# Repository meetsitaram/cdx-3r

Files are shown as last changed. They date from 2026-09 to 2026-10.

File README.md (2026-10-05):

# CDX-3R

A right-arm exoskeleton made of 3D-printed parts, PVC pipe and off-the-shelf bearings, designed around a
3D scan of the wearer's body. **3R** = three revolute joints on the right arm: shoulder abduction, shoulder
flexion and elbow flexion.

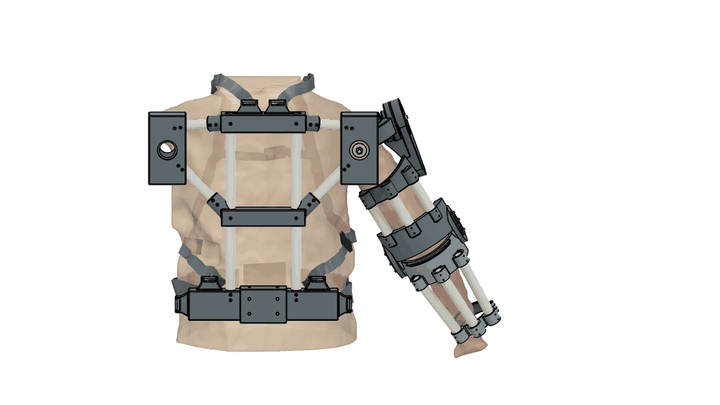
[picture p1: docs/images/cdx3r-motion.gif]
CDX-3R: shoulder and elbow motion


*Elbow to 100 degrees, shoulder forward to 70 and out to 45, back to rest; the scanned arm moves with the exo. Rendered from the Fusion models. [Video](docs/images/cdx3r-motion.mp4)*

> Work in progress. The passive structure (frame, joints, harness) is designed and being test-printed;
> actuation (motors, cables, battery) is not designed yet. Not a certified device.

## How it works

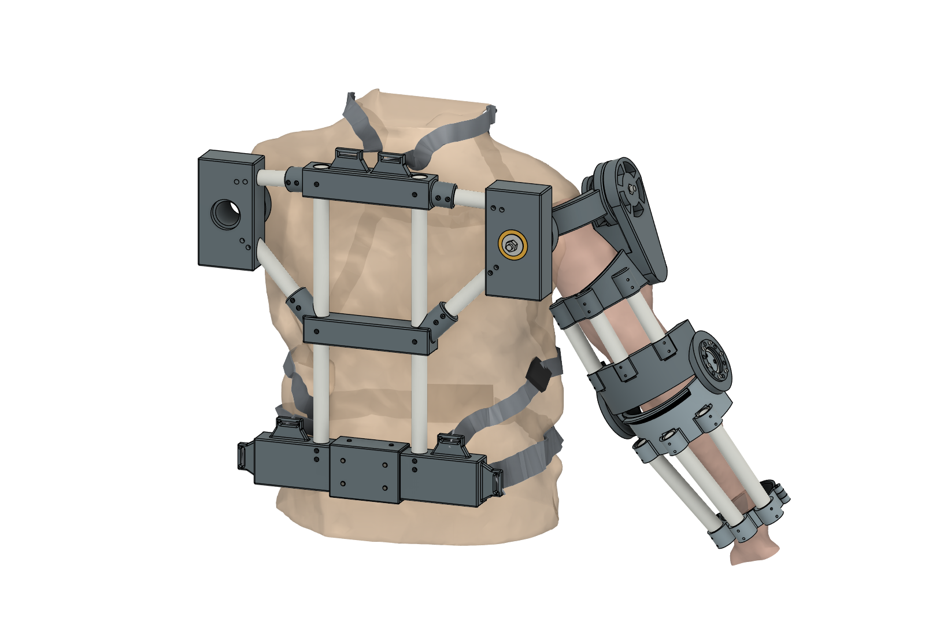
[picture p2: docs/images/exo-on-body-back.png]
Back view: frame, shoulder hinges, arm


**Back frame.** Two vertical PVC pipes (21.5 mm OD) form the backbone. They're held by printed top, mid and
bottom joints and braced to a mount block behind each shoulder by an upper beam and a diagonal, a triangulated
frame that carries the arm's loads into the back and the waist belt. The frame is symmetric (the left side is a
Fusion mirror of the right) so the weight sits centred. The left mount block is free for a battery or a future left arm.

**Harness.** Worn like a backpack: two shoulder straps, a sternum strap and a waist strap, all 1" webbing
with side-release buckles, through six printed strap tabs on the frame.

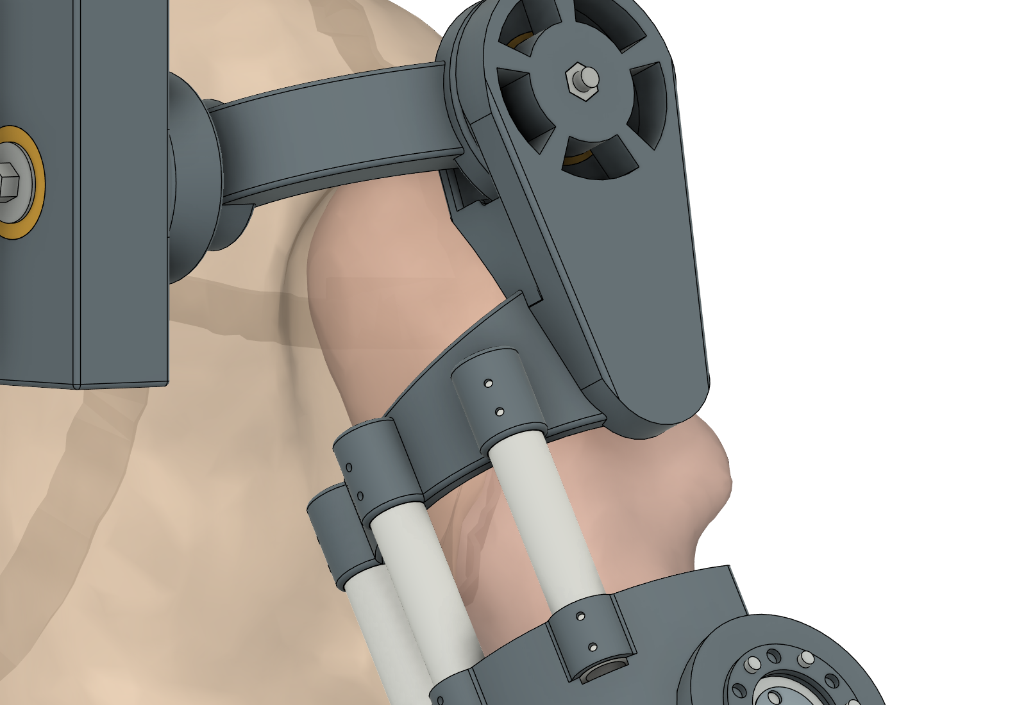
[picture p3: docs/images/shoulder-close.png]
Shoulder: abduction and flexion hinges, upper-arm link


**Shoulder (2 joints).**
- *Abduction* (arm out to the side): a hinge behind the shoulder on 2 × 6806 bearings in the mount block,
  clamped by an M8 through-bolt. A curved yoke carries it round the back of the shoulder.
- *Flexion* (arm forward/back): a hinge on the outside of the shoulder on 2 × 6808 bearings in the yoke's
  Ø88 housing (the same size as the elbow hub).
- Both hinge axes pass through the shoulder joint's centre, so the exo moves with the arm instead of sliding on it.
- *Upper-arm link:* one printed piece: a fork round the flexion hinge (spoked, so the bearing shows), a
  Y-gusset and a pipe head that holds the three upper-arm pipes in blind sockets. It also acts as the
  backward stop at about -25 degrees.

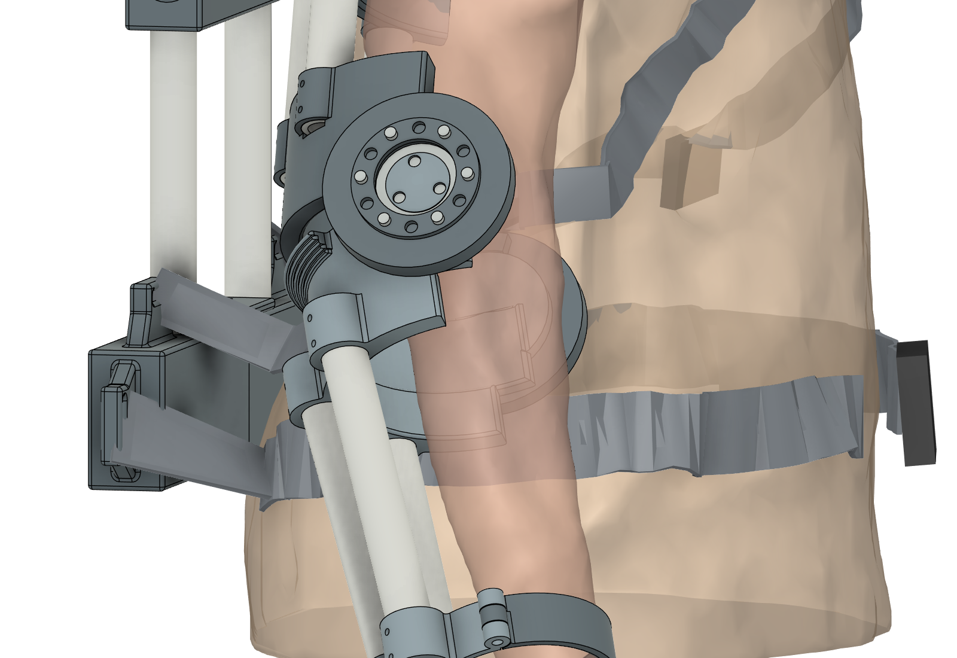
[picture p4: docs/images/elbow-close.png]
Elbow: two-sided bearing joint


**Elbow.** Upper-arm and forearm units are three rear PVC pipes each, joined at a two-sided hinge on
2 × 6806 bearings with bolted axles and spoked covers. Built-in stops at straight and 135 degrees flexion. Nothing
hard sits on the front of the arm near the elbow, so there's no biceps pinch. A hinged wrist ring with a cuff holds
the forearm.

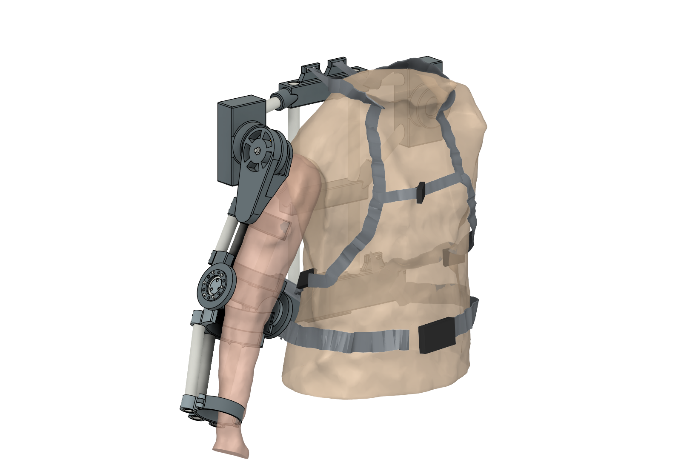
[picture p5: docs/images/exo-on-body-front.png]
CDX-3R on the scanned body


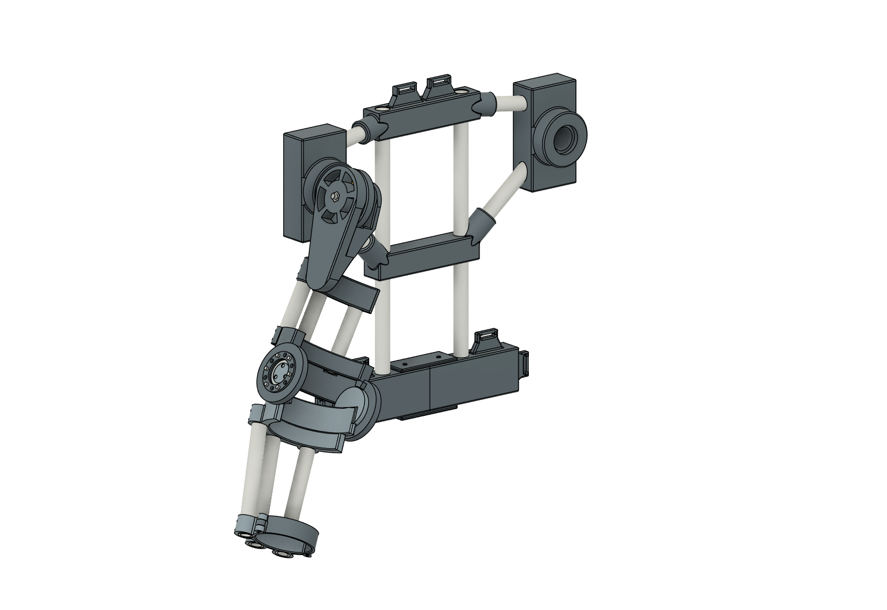
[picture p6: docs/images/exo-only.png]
Exo only


## Fitted to a body scan

The wearer was captured as a Gaussian splat. `cad/scan/` turns it into a clean body mesh with landmarks
(shoulder joint centre, elbow, wrist). The layout and every part are checked against it: collisions,
clearance to the body at rest (the arm rests at 20 degrees abduction) and over the shoulder's range
(abduction 20–60 degrees, flexion -20 to 120 degrees), plus the elbow's 0–135 degree sweep.

## Build it

| What | Where |
|---|---|
| Step-by-step assembly guide, with animations and PVC cut lengths | [docs/ASSEMBLY.md](docs/ASSEMBLY.md) |
| Parts to buy (bearings, screws, inserts, webbing), with links | [BOM.md](BOM.md) |
| Print files (Bambu P1S, PETG), orientation, assembly | [prints/shoulder-back-v2/](prints/shoulder-back-v2/) and [prints/elbow-test-v10/](prints/elbow-test-v10/) |
| Fusion models | [cad/fusion/models/](cad/fusion/models/) (`cdx-3r-shoulder-back.f3d`, `cdx-3r-elbow-concepts.f3d`) |
| Scripts that build the models | [cad/fusion/](cad/fusion/) (`shoulder.py`, `concepts.py`, `fxlib.py`) |
| Body-scan pipeline | [cad/scan/](cad/scan/) |
| Lessons learned (read before changing the design) | [cad/fusion/LESSONS.md](cad/fusion/LESSONS.md) |

## Not done yet

- Actuation: motors, cable drive, battery, controller.
- Wrist-cuff latch (a magnet-assisted snap latch is planned).
- Dedicated shoulder stop pads (abduction 60 degrees, flexion 120 degrees).
- Shoulder-girdle motion (shoulder blade forward/back and shrug): parked, see [docs/extensions/shoulder-girdle-dof.md](docs/extensions/shoulder-girdle-dof.md).

## Website

The design portal site lives in `src/`:

```bash
npm install
npm run dev     # http://localhost:8080
```

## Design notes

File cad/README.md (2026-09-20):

# CDX-3R CAD — piece by piece

Not a 7-axis arm. Three revolute joints, right side.

| Order | Stage | Status |
|---|---|---|
| 1 | **Elbow** — hinge, antagonist sheave, cuffs | `elbow/` |
| 2 | **Shoulder** — flexion (lateral) + abduction (posterior) | `shoulder/` |
| 3 | **Backpack** — 3 winches, battery envelope, ODrive S1 | `backpack/` |
| 4 | **Connect** — one system, saddle + hip belt take the weight | `system/` |
| 4 | Connect — Bowden runs, cable comb, hard stops as a system | after pack |
| 5 | **Armor** — circular window around the sheave | `armor/` |

**Rule:** metal takes the load. Print the fixtures that hold the metal.

Open `elbow/` first. Do not print the whole suit.

## Current revision

[Revision C — articulated assembly](system/README.md#revision-c--articulated-inspection-model)
adds three joint controls, moving shells and hardware, and approximate flexible
cable routing to the system viewer.

[Revision B — rebuilt shells](armor/README.md) adds segmented shoulder armor,
tapered arm panels and a passive wrist collar, with a synchronized full assembly.

```bash
python -m pip install -r cad/requirements.txt
python -B cad/build.py
python -B -m unittest discover -s cad/tests -v
python -B cad/render_previews.py
```

The scripts work from this checkout without `/workspace` paths. STL units are mm.
Both local and public exports are produced from the same normalized meshes.
`cad/render_mesh.py` renders the actual STL surfaces locally with a depth buffer.

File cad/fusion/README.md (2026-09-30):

# CDX-3R in Autodesk Fusion

Fusion models built from this repo's CAD, and the scripts that build them. Scripts run inside
Fusion (Fusion MCP or Utilities > Scripts and Add-Ins); units are mm.

## Models (`models/`)

| File | What |
|---|---|
| `cdx-3r-elbow-concepts.f3d` | Current elbow design (concept B): PVC-pipe arm units (3 rear pipes, 2 self-tapping screws per pipe joint, forearm tapering to the wrist), two-sided 6806 bearing joint with bolted axles (pilot + 3 × M3), M3 covers, elbow shells, hyperextension ledge and 135° flexion stop, side-opening wrist cuff, rounded skin-side edges, fit coupons, and all bought hardware modelled. Repeated features are patterns / mirrors of one seed. Built by `concepts.py`. |
| `cdx-3r-shoulder-back.f3d` | Shoulder + back system on the exoarm2 body scan: PVC back frame (mirrored L/R), strap anchors, split bottom node with U-channel splice, abduction mount blocks (2 x 6806, M8 through-bolt), yoke, one-piece upper-arm link (6808 fork hinge, spoked hub, pipe head + brace wall), all hardware, the elbow (copied, posed at the scanned 12 deg), scan reference and harness illustration. Built by `shoulder.py`. |
| `cdx-3r-full-arm.f3d` | The whole existing CDX-3R (elbow, shoulder, backpack, system, armor, wearer) rebuilt as Fusion solids from `cad/*/build_stl.py`, plus the imported reference STLs. Built by `build.py`. |

Open with Fusion: File > Open > Open from my computer.

## Scripts

- `concepts.py` - the elbow concept. Edit `P` at the top (arm sizes, pipes, bearing, axle, screws,
  cuff, stops) and run `concepts.main()`; it rebuilds and re-runs the collision sweeps (elbow
  0-135°, cuff 0-100° at elbow 0° and 90°). The stop, pipe-path, hardware-fit and soft-tissue
  checks used during design are in the session notes of the test-print READMEs.
  `export_stls()` writes the test-print set.
- `build.py` + `fxlib.py`, `elbow.py`, `mech.py`, `armor.py` - the full-arm rebuild, one stage per
  subsystem; `check` compares every part with its reference mesh (all 114 layers within 0.85 mm).

Runner (Fusion MCP / script):

```python
import sys, importlib
sys.path.insert(0, r'<repo>\cad\fusion')
import fxlib, concepts
for m in (fxlib, concepts): importlib.reload(m)
def run(context): concepts.main(('B',))
```

Test prints: `prints/elbow-test-v10/` and `prints/shoulder-back-v2/` are current (see its README). Earlier folders are kept for
reference; each README says what changed.

Shoulder + back (`shoulder.py`): run `main()` (frame), then `main2()` (moving side), `place_elbow()`, `add_harness()`
and `show_reference_smooth()`; `export_print(dir)` writes the print set. Rebuilding the frame removes the arm side, so
always run `main2()` after `main()`. Keep each call short (the MCP call times out on very long runs). Lessons learned
building both are in `LESSONS.md`; the body-scan pipeline is in `cad/scan/`; bought parts are in `BOM.md` at the repo root.

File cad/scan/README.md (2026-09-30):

# Body scan → exo layout (exoarm2)

These scripts turn the exoarm2 Gaussian-splat body scan into a clean body mesh, lay out the exo on it and check clearances.
The working copy (with the large scan meshes) lives in `C:\Users\PC\projects\exoarm2-scan`. `cad/fusion/shoulder.py`
reads `exoarm2-scan/out/...` from there. This folder is the versioned copy of the scripts plus `layout/layout.json` (the
landmarks and frame points the Fusion model is built from).

The frame is mm, X forward, Y up, Z right; floor at Y = 0. Tools need Python 3.12 with numpy, scipy, open3d, trimesh, manifold3d,
shapely, scikit-image and matplotlib.

| Script | What |
|---|---|
| `splat.cs` | C# SPZ decoder/renderer (no Python needed) |
| `body.py` | splat → body point cloud, levelled and yaw-aligned (`body_pts.ply`) |
| `solid.py` / `mesh.py` | watertight body solid (voxel close + fill + marching cubes) |
| `landmarks.py` / `sections.py` | slice measurements and section plots (shoulder GH, elbow, wrist) |
| `layout.py` | layout + distance fields; rest pose (20° abduction); writes `layout.json` |
| `trim.py` | Fusion reference meshes (torso hips → neck without head/left arm; right arm to wrist) |
| `harness.py` | webbing + buckles illustration routed over the torso |
| `check_fusion.py` | clearance of the Fusion-exported parts to the body + shoulder ROM sweep |
| `com.py` | mass and centre of mass |
| `rest.py`, `study_ua.py`, `render.py`, `viewer.py`, `fmcp.py` | shoulder-rest study (dropped), upper-arm study, renders, three.js viewer, a direct Fusion MCP client (fallback only) |

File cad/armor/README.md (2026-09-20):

# Revision B — shoulder-to-forearm shells

The operator-view reference drives the panel coverage: a segmented shoulder cap, long tapered upper-arm and forearm panels, contrasting borders, narrow light strips, an open elbow joint, and a passive wrist collar.

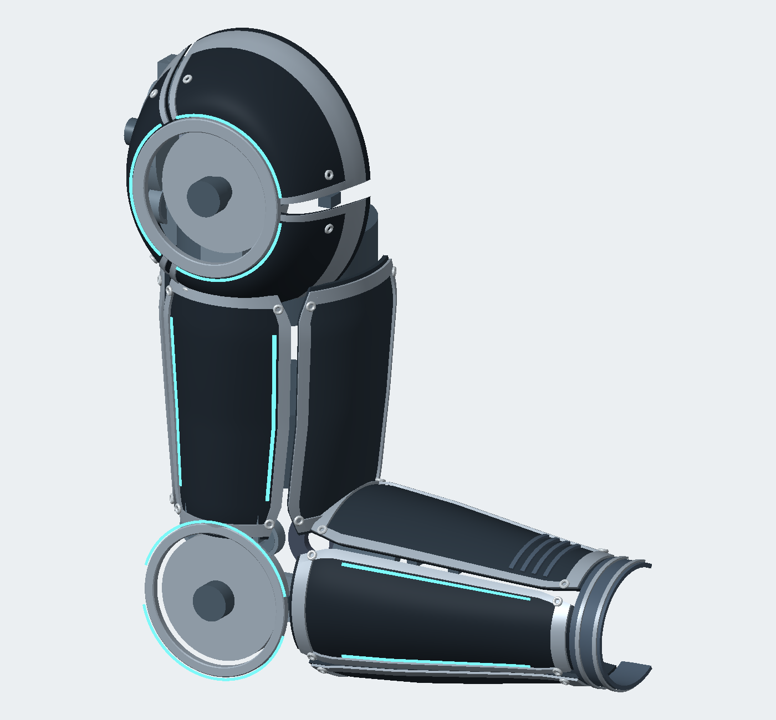
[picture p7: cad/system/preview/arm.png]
Actual revised CAD, with the mechanical joints


The image is rendered directly from the exported STLs. It is not an AI-generated replacement for the CAD.

## Geometry and files

- Three separately closed shoulder panels surround the actual flexion axle. There is no duplicate cosmetic sheave stack.
- The main upper-arm panel spans 178 mm along the limb, increased from 108 mm. The forearm panel spans 201 mm, increased from 106 mm.
- Front and rear wings wrap around each limb with gaps between panels. Borders and light strips follow the same parametric surfaces.
- The main limb walls are 3.2 mm; the shoulder panels are 3.5 mm. The wrist collar is passive.
- Each primary panel has its own `print_fairing_*.stl`. `print_fairing_ua` and `print_fairing_fa` are center panels; `_front` and `_rear` are separate wings. `print_fairing_pack_tub` is now the left pack rail, with a separate right rail, crown, bridges and battery lid.
- Hardware heads, trim and lights are separate assembly layers. The visible fasteners are reference details; mounting holes, inserts, brackets and motion clearance still need a fabrication-detail pass.

Source: [build_stl.py](build_stl.py). Common dimensions: [params.json](../params.json) and [design.py](../design.py). Surface construction: [surfaces.py](../surfaces.py).

## Rebuild and inspect

From the repository root:

```bash
python -B cad/build.py
python -B -m unittest discover -s cad/tests -v
python -B cad/render_previews.py
```

Install the packages in `cad/requirements.txt` if needed. The outputs in `cad/*/stl` and `public/cad/*` are generated together, with matching manifests. The web viewer uses these manifests and retains a complete combined assembly if any colored layer fails to load.

The original five geometry checks cover export synchronization and completeness, closed single-solid shell topology, pack envelope separation, joint/window alignment, and sleeve coverage/cuff clearance. They do not establish collision clearance through the full motion range or structural load capacity.

## Layout changes supporting the shells

Both flexion axes are parallel to world Z; the elbow is directly below the shoulder. The previous whole-elbow 45° yaw is removed. The abduction sheave and its mounting ring now use world X as their rotation axis.

The pack has three transverse winch bays at 90 mm spacing, controllers behind the motors, and a separate lower battery compartment. The existing compact battery envelope has been rotated to 220 × 76 × 52 mm. A specific battery part remains to be selected; the old Hailong purchase reference did not match that envelope.

## Articulated integration

[Revision C](../system/README.md#revision-c--articulated-inspection-model) assigns each
panel and its trim, lighting and fasteners to the appropriate joint. The shell
contours and printable parts are unchanged; grouping layers are now split by
rigid attachment. Use the system viewer to inspect movement with the mechanisms.

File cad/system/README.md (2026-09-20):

# CDX-3R system

Elbow + shoulder + backpack as **one structure**.

The exo does **not** hang on the arm.

```
  [pack] --yoke--> [SADDLE on trapezius]
                       |
                    UA beam (lateral)
                       |
                    elbow
                       |
                  PARK REST  (forearm sits here)
                       |
                    HIP BELT
```

- **Amber saddle** — rests on the shoulder. This is the rest position for the exo.
- **Yoke** — saddle load goes into the pack, then the hip belt.
- **Cuffs** — couple assist torque to the limb. They are not a hanger.
- **Red park rest** — forearm shelf in rest. You can take your arm out. The exo stays.

If the biceps are holding the suit, the load path is wrong.

## Revision B

The full assembly now includes every current shell and mechanism layer. The
shoulder and elbow use shared datums from `cad/design.py`; all exported views
use the same work pose. The elbow flexes forward without the former 45° yaw.
The pack has separated winch bays, rear controllers and a lower battery envelope.
The system harness replaces disconnected subsystem cable extensions.

See [shell revision and verification](../armor/README.md).

## Revision C — articulated inspection model

The portal's **Motion → Articulated assembly → Load 3D** view now moves the
actual CAD layers. It provides shoulder abduction, shoulder flexion and elbow
flexion sliders, four pose presets, a motion sequence, shell visibility, joint
axis arrows and a fit-view button. The same controls appear in the full system
viewer. Individual elbow/shoulder kit viewers remain static part inspections.

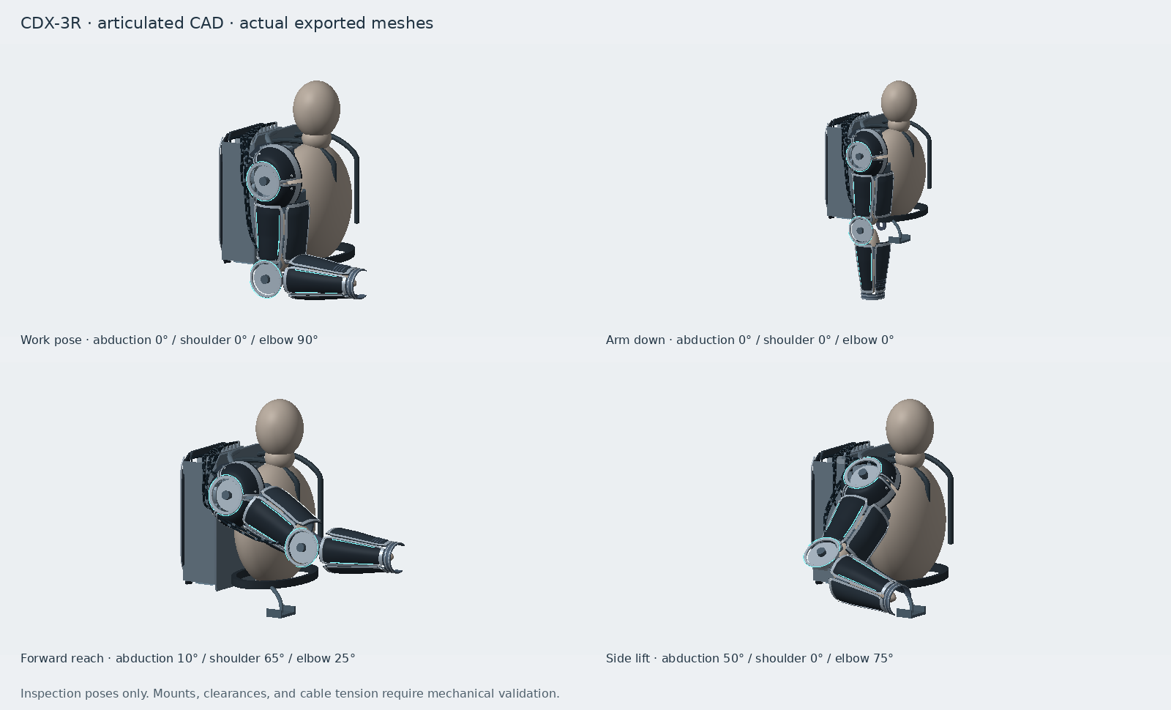
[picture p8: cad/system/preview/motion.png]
Actual CAD in four joint poses


The 114 assembly layers contain the same 106,020 triangles as the previous
79-layer assembly. The additional layers separate upper-arm and forearm trim,
fasteners and lights, the two shoulder joints' fittings, the mannequin limbs,
and individual harness routes. Shell contours and print parts are unchanged.

### Joint convention

The source STLs stay in the work pose: upper arm down, forearm forward. The
exported `asm/colors.json` contains a `motion` block with joint hierarchy,
rest-world axle origins, axes, layer ownership and flexible routing weights.
`cad/motion.py` is the source of that contract. The Three.js viewer builds nested
joint groups from it; it does not infer a hinge from each mesh's bounding box.

| Joint | Parent | Positive direction | Inspection range | STL rest angle |
|---|---|---|---|---|
| Shoulder abduction | Torso/pack | Outboard, about −X | 0–60° | 0° |
| Shoulder flexion | Abduction yoke | Forward, about local +Z | 0–90° | 0° |
| Elbow flexion | Upper arm | Bend from extension, about local +Z | 0–135° | 90° |

The shoulder cap belongs to the abduction yoke. Upper-arm panels and their trim
follow shoulder flexion; forearm panels, cuff, distal plate and passive wrist
follow elbow flexion. The pack, straps, saddle and parking cradle stay fixed.
The body ghost is split so its two limb segments follow the same joints.

Flexible housings and collars blend between their fixed pack attachment and
moving joint attachment. Exposed cable shapes also deform for inspection.
This approximation does **not** preserve cable length, model tendon tension,
solve sheave contact, or verify bend radius. The ranges above are provisional
inspection ranges; they are not certified hard-stop limits or collision-free
motion envelopes. Visible fasteners still need mating mounts and holes.

### Verify and reproduce

```bash
python -B cad/build.py
python -B -m unittest discover -s cad/tests -v
pnpm run test:cad-motion
pnpm run typecheck
pnpm run build:dev
python -B cad/render_motion.py             # four-pose evidence sheet
python -B cad/render_motion.py --animate   # also generate a fixed-camera GIF
```

The nine Python checks cover the earlier geometry/export checks plus ownership,
rest-pose identity, joint closure and segment lengths, and routing endpoints.
Seven TypeScript checks exercise the actual Three.js hierarchy, combined angle
sweeps, shell visibility, malformed metadata, bounded inputs, and cable endpoints
without incremental-transform drift. These checks do not test physical loads
or prove surface collision clearance. There is no hardware-control connection.

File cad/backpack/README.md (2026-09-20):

# CDX-3R backpack

Revision B: three transverse winches in separate bays, controllers on the backplane, and a lower compact-battery compartment. The frame is 250 × 392 × 120 mm.

The modeled battery is an **unselected 220 × 76 × 52 mm envelope**. It is the previous compact block rotated into the lower bay, not a Hailong battery. The final battery selection and its manufacturer geometry remain open.

## Buy (real)

| Qty | Part | Why |
|---|---|---|
| 3 | [ODrive S1](https://shop.odriverobotics.com/products/odrive-s1) $149 | One axis each. 12–48 V, 40 A. |
| 3 | [D6374 150 kV](https://shop.odriverobotics.com/products/odrive-custom-motor-d6374-150kv) $119 | 10 mm shaft, 8 mm rear for encoder. |
| 3 | PLE60 10:1 planetary (14 mm out) | Drum torque. 10 mm in matches D6374. |
| 3 | [CUI AMT212](https://www.cuisensors.com/) on the rear 8 mm | ODrive S1 encoder. |
| 1 | Compact 48 V battery — selection pending | Must fit the allocated 220×76×52 mm envelope or the pack must be resized. |
| 2 | XT90 | Battery to bus. |
| 6 | M5×0.8 barrel adjusters + 5 mm Jagwire ferrules | Bulkhead. Antagonist pair per axis. |
| 6 | 608-2RS [6455K44](https://www.mcmaster.com/6455K44/) | Drum support. |

## Gears

Printed drum, 20 mm pitch radius, on the 14 mm planetary output.

| Joint | Cable T (5 kg) | Drum τ | Motor τ after 10:1 |
|---|---|---|---|
| Elbow | 450 N | 9 N·m | 0.9 N·m — D6374 is fine |
| Shoulder flex | 840 N | 17 N·m | 1.7 N·m — peak ok |
| Shoulder abd | same order | same | same |

15 kg at the shoulder is **not** this gearbox. That needs 1/8 in rope and a bigger reducer.

## Print

Frame, compact-battery sled, 3 drums, bulkhead plate. Do not print motors, S1, battery, planetaries.

## Verified layout

Winch row centers are Y=100, 10 and −80 mm. The 75 mm motor envelopes have 15 mm between rows. The battery occupies Y=−221 to −145 mm, below the bottom winch at Y=−117.5 mm. The 16 mm controller envelopes occupy Z=10–26 mm; winch envelopes start at Z=31.5 mm. These are geometric envelope checks, not supplier verification.

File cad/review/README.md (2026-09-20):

# CAD versus generated visuals

**Historical baseline, before Revision B.** The current implementation is described in [the shell revision](../armor/README.md). The saved measurements and images below intentionally show the earlier CAD.

Reviewed 2026-09-20. The current work provides a reusable component layout and early armor studies. A substantial pass on packaging, body-fitting surfaces, and assembly interfaces is still needed to resemble the generated imagery. Better materials and lighting will help presentation, but cannot supply the missing geometry.

This review compares the repository's generated stills with its current Python geometry and served STL layers. The new images below render existing geometry with neutral materials; they are not proposed redesigns. Views and poses differ from the concept images, so this is a qualitative design comparison, not a pixel similarity measurement. No mechanical dimensions or design geometry were changed for this review.

## What is already present

- Right-arm elbow hinge, cuff geometry, sheave and fastener references, cable anchors and fairleads.
- Shoulder flexion and abduction assemblies, upper-arm beam, saddle, yoke, hip belt and forearm rest.
- Three backpack winch envelopes, battery and controller envelopes, bulkhead and cable runs.
- Separate shoulder, upper-arm, forearm, scapula and backpack fairings, plus trim and light-strip placeholders.
- Editable procedural geometry and separate STL layers. This is useful starting material, although it is not a fully constrained solid assembly.

## How far the appearance is from the references

| Area | Generated reference | Current CAD | Work needed |
|---|---|---|---|
| Overall silhouette | Close-fitting armor with continuous visual transitions between shoulder, arm, wrist and pack | Sparse frame, short shell patches, cylindrical body stand-in and a rectangular backpack | Establish a fitted body envelope, coordinated joint centers and consistent proportions |
| Shoulder | Sculpted segmented cap with overlapping metal trim, recessed mechanism and integrated cable exits | Spherical window shell, simple rings and large block-shaped supports | Redesign cap profile, panel boundaries, trim and attachment interfaces around the actual shoulder mechanism |
| Upper arm / forearm | Long tapered panels, wraparound coverage, seams, ribs and layered joint transitions | Upper-arm shell spans 108 mm; forearm shell spans 106 mm along their local limb axes | Extend and shape the panel system, with deliberate elbow and wrist transitions; these lengths are not directly measurable from the generated images |
| Wrist / hand | Articulated-looking gauntlet and plated hand in the hero and operator views | No corresponding wrist/hand armor assembly found in the CAD generators | Add passive wrist/hand plating if that visual is in scope; keep it separate from the three powered axes |
| Backpack | Contoured shell, visible organized drive modules and a defined battery compartment | 220 × 280 × 80 mm rectangular frame; internal layout and decorative windows disagree | Resolve the physical component layout first, then design the cover around it |
| Cables / interfaces | Bundled curved runs, clamps, connectors, panel mounts and trim | Straight-segment tube approximations and scattered placeholder fittings | Model continuous routes, attachment points and service access in the same assembly coordinates |
| Finish | Carbon weave, metal edges, fasteners, blue lighting and controlled photographic lighting | Flat material colors and coarse preview lighting | Add rendering detail after the silhouette and interfaces are settled |

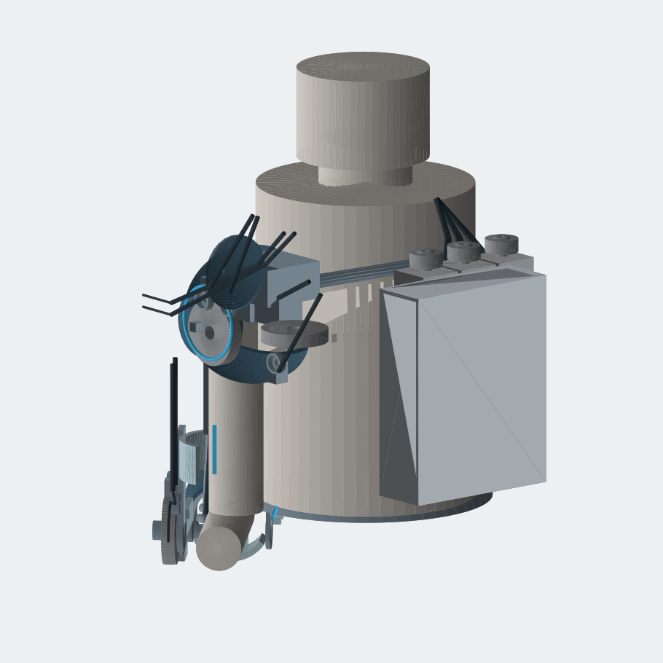
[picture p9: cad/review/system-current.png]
Existing full assembly, all manifest layers, neutral materials


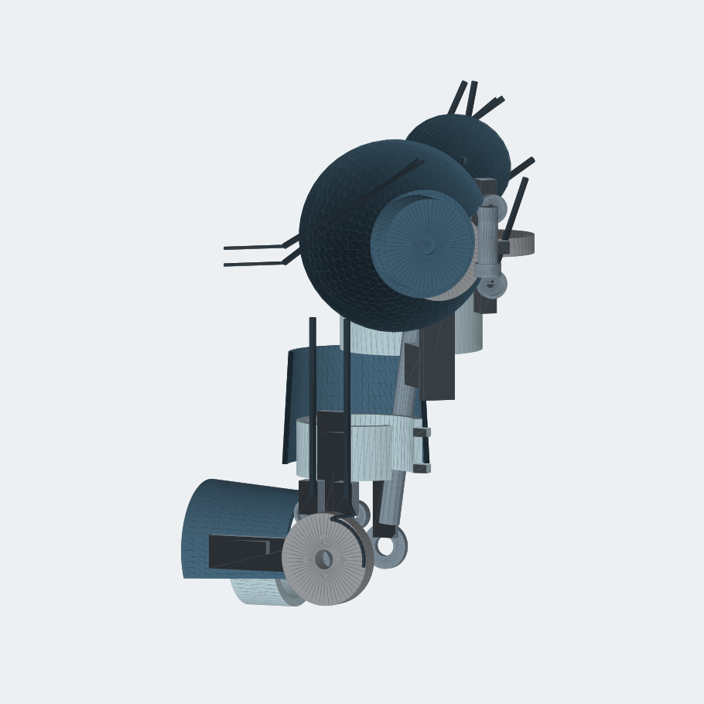
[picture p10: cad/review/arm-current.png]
Existing shoulder and arm geometry, isolated


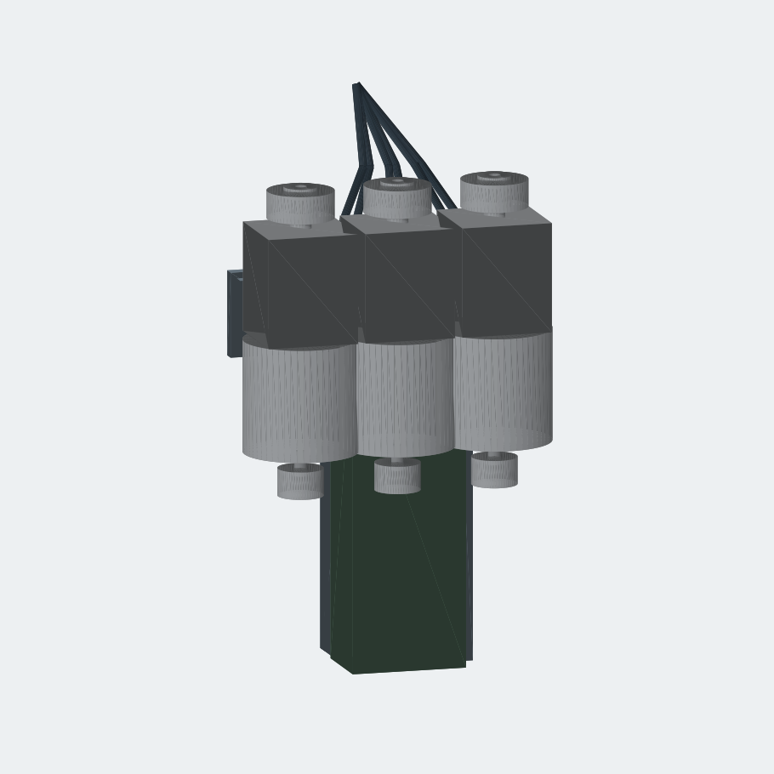
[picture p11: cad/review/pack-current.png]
Existing backpack internals, frame removed to expose layout


## Specific issues that affect the next revision

### The displayed and exported assemblies differ

The served per-part STL triangles match the current Python-generated geometry for all five kits. However:

- `cad/system/stl/assembly_worn.stl` has **38,180 triangles**, while `public/cad/system/assembly_worn.stl` has **52,060**. The local system assembly lacks the nine `ar_*` armor layers present in the served system.
- The web viewer's full-system layer list contains **32 of the 65 layers in the served manifest**. It removes the full gray fallback after the first colored layer loads. Yokes, bearings, fasteners, several cable runs and other components therefore disappear from the final colored view. Failed layer loads are also silently ignored.
- The system preview renderer explicitly excludes all armor layers from its `worn` view. The existing still is not an all-layer view.
- All five geometry generators and preview scripts use absolute `/workspace/public/cad/...` output paths, which do not point into this checkout.

Sources: [viewer](../../src/components/cdx/cad-viewer.tsx), [system generator](../system/build_stl.py), [system preview renderer](../system/render_previews.py).

### The backpack needs packaging work before surfacing

These measurements describe the repository's modeled envelopes, not independently verified commercial hardware:

- Motors are modeled at **75 mm diameter on 65 mm centers**. Adjacent parallel motor bodies overlap by 10 mm along their centerline.
- The central motor occupies the same space as the battery block: its body runs from Y=18 to 92 mm around X=0, Z=42 mm, inside the battery's Y=-125 to 95 mm range and overlapping its X/Z section.
- A placed winch extends to **Y=192.5 mm**, while the frame ends at **Y=140 mm**: 52.5 mm extends beyond the top of that frame.
- The modeled battery is **76 × 220 × 52 mm**, while the backpack README names a **367 × 90 × 111 mm** Hailong envelope. These are different packaging assumptions.
- The armor has three windows stacked along Y and facing outward along the pack's Z axis. The drive modules are placed side by side along X with their shafts along Y. The cover windows therefore do not expose the drive faces as the concept suggests.

Sources: [backpack geometry](../backpack/build_stl.py), [backpack README](../backpack/README.md), [armor geometry](../armor/build_stl.py).

### Armor and joints are still independent studies

The armor generator adds its own two coaxial shoulder sheaves at X=14, Y=10, while the mechanical shoulder flexion sheave is centered at X=0, Y=0. The system includes both. The cap and bezel should reference the real mechanism instead of adding another mechanism to achieve the appearance.

The shoulder source describes abduction about X, but builds that sheave with `rx(90)`, which rotates the cylinder's Z axis onto Y. That axis convention needs reconciliation before articulating the assembly.

The current generators place the assembly in fixed poses. This review did not perform a range-of-motion, cable travel, collision sweep, structural analysis or physical fit test.

### Some “print” meshes need topology repair

An edge audit of the generated armor meshes found:

| Mesh | Closed surface | Finding |
|---|---|---|
| Scapula fairing | No | 112 boundary edges |
| Backpack tub | No | 240 boundary edges |
| Upper-arm, forearm and deltoid fairings | Yes | Inconsistent triangle winding |
| Backpack lid and deltoid bezel | Yes | Edge closure and winding checks pass; this does not prove fit or that each export is one connected part |

`polar_plate()` creates inside and outside surfaces without closing the perimeter or window walls. Adding panels together with `Mesh.add()` also does not perform a solid union. The frame, for example, has 12 non-manifold edges after coincident vertices are merged.

See [audit results](audit.json). The saved JSON preserves the baseline measurements. Running `python cad/review/audit_cad.py` now audits the current normalized geometry into `audit-current.json`, using NumPy and trimesh. The inspection renders can be reproduced with `MPLCONFIGDIR=/tmp/cdx-review-mpl python cad/review/render_cad.py` using NumPy and Matplotlib. The audit imports generator functions without invoking their export routines.

## Reference decisions

The generated images do not describe one consistent machine:

- [Hero](../../public/gallery/hero.jpg): three prominent circular pack faces arranged across the upper back and extensive hand plating.
- [Pack detail](../../public/gallery/pack.jpg): three drive modules arranged vertically with a separate lower battery compartment.
- [Side](../../public/gallery/side.jpg): a much more exposed arm frame and another pack treatment.
- [Operator view](../../public/gallery/first-person.jpg): useful guidance for panel coverage, cable bundles, elbow transitions and the passive gauntlet.

Recommended starting interpretation: use the operator view for arm coverage and surface language, the pack detail for the pack's visual organization, and the hero for finish and overall character. The final pack layout must follow actual component envelopes; none of these images supplies reliable dimensions or proves mechanical feasibility.

## Concrete route to the next CAD revision

1. **Make one reproducible assembly.** Use checkout-relative output paths; synchronize local and served geometry; load the complete layer manifest; centralize wearer dimensions and joint transforms. Done when the local STL, web view and all-layer render show the same parts in the same pose.
2. **Resolve the physical layout.** Reconcile shoulder axes, remove duplicate cosmetic mechanisms and repack the motors, electronics and selected battery without overlap. Done when real component envelopes fit their allocated space and drive faces align with intended openings.
3. **Build the visible shell system.** Shape a shoulder cap, tapered upper-arm and forearm panels, passive wrist transition and contoured pack. Add consistent overlaps, borders and panel gaps around the mechanism. Done when neutral-material front, side and rear views reproduce the chosen reference's coverage and silhouette.
4. **Detail assembly and motion.** Add mounts, seams, fastener holes, cable guides and service access. Repair topology and inspect neutral, 90° elbow-flexion and raised-arm poses for interference. Done when the chosen clearances are demonstrated across the defined motion range.
5. **Finish presentation.** Add carbon/metal materials, restrained lighting accents and matched camera views. Review these against the chosen generated stills after geometry is settled.

The first useful modeling deliverable is a coherent, fully visible assembly with corrected packaging and a new shoulder-to-forearm shell pass. That will close more of the gap than polishing the existing preview images alone.

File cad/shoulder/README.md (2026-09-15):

# CDX-3R shoulder — 2R

Two revolute joints, both **outside** the arm.

| Axis | Sheave | Where | Axis direction |
|---|---|---|---|
| Flexion | McMaster 3434T121 (gold) | **Lateral** of the GH joint | ML, like the elbow |
| Abduction | McMaster 3434T121 (orange) | **Posterior**, toward the pack | AP |

Elbow Bowden (cyan) **passes the comb** on the scapula pad. It does not wrap either shoulder sheave.

## Pose

90° shoulder flexion (upper arm forward). 0° abduction. Cables go **up/back to the backpack**, not down the arm.

## Physics (same r = 38.1 mm)

Lever is longer than the elbow — crate is ~0.65 m from GH.

| Crate | τ at shoulder | Cable T |
|---|---|---|
| 5 kg garage | 32 N·m | 840 N — Jagwire is tight |
| 15 kg | 96 N·m | 2500 N — 1/8 in 7×19, not PETG |

## Buy (per shoulder, on top of the elbow kit)

- 2× [3434T121](https://www.mcmaster.com/3434T121/)
- 2× [91273A274](https://www.mcmaster.com/91273A274/) 3/4 in shoulder screws
- 4× [6455K44](https://www.mcmaster.com/6455K44/) 608-2RS
- Same nylocks / washers / M8 heat-sets as the elbow

## Print

scapula pad, abduction yoke, flexion yoke, deltoid cuff, cable comb, Bowden anchors, hard stops.

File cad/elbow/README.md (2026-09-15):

# CDX-3R elbow

The arm goes **through the cuffs**. The sheave does **not**.

This is an orthopedic-brace layout, not a pulley stuffed inside the elbow.

```
 medial plate                         lateral plate + SHEAVE
     |                                        |
     |     [ upper cuff  ○ arm ○ ]            |
     |______________ hinge axis ______________|
     |     [ forearm cuff ○ arm ○ ]           |
```

- Origin = anatomical flexion axis (through the epicondyles).
- Cuffs: C-rings, open medial, straps. Inner volume is the wearer.
- Lateral plate: sagittal, outboard of the cuff OD. McMaster sheave lives here.
- Medial plate: light hinge only. No through-bolt through flesh.
- 90° work pose in the assembly: upper arm −X, forearm +Y.

## Attach the real hardware

Stack, outboard → inboard:

1. **91273A274** 3/4 in shoulder screw (head outboard)
2. 3/4 in washer
3. **3434T121** sheave (sleeve bearing already in it)
4. Lateral plate (printed) — 19.2 mm hole
5. 3/4 in washer
6. **90640A125** nylock

Cable fairleads: press **6455K44** (608-2RS) into the two printed cups on the plate. **M8×25** through the bore into an M8 heat-set.

Same 3/4 in hole takes **3434T157** (sealed ball, ~$133) if you want to upgrade the sheave later. Do not reprint.

## Physics

Pitch radius r = 38.1 mm (3434T121). Lever ≈ 0.35 m.

| Crate | τ | Cable T |
|---|---|---|
| 5 kg garage | 17 N·m | 450 N — Jagwire |
| 15 kg | 51 N·m | 1350 N — 1/8 in 7×19 |

## Human (edit `../params.json`)

290 / 260 / 90 mm · cuff ID 105 / 95 mm · ROM 0–135°.

## Buy / print

See the site **Build** list. Do not print `ref_*` files.

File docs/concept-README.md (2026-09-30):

# CDX-3R

> **Archived concept README.** This was the original concept portal page (renders and clips are concept art, not the current CAD). The current design is described in the [main README](../README.md).

Cable-driven right-arm exoskeleton. **3R** = three revolute axes on the right arm (shoulder flexion, shoulder abduction, elbow flexion). Wrist plating is passive.

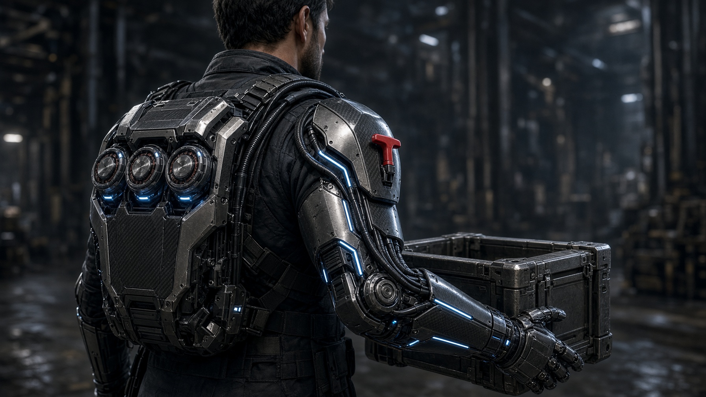
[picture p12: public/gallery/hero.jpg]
CDX-3R holding a crate


This repo is the design portal: architecture, physics, cable drive, motion clips, safety, gallery, cost, and sponsor kit.

> Concept design. Not a certified build. Structural analysis, e-stop testing, and battery safety review still required.

## The machine

Motors in the backpack. Bowden cables over the right shoulder. Three powered revolute joints. Left hand stays free for the T-handle.

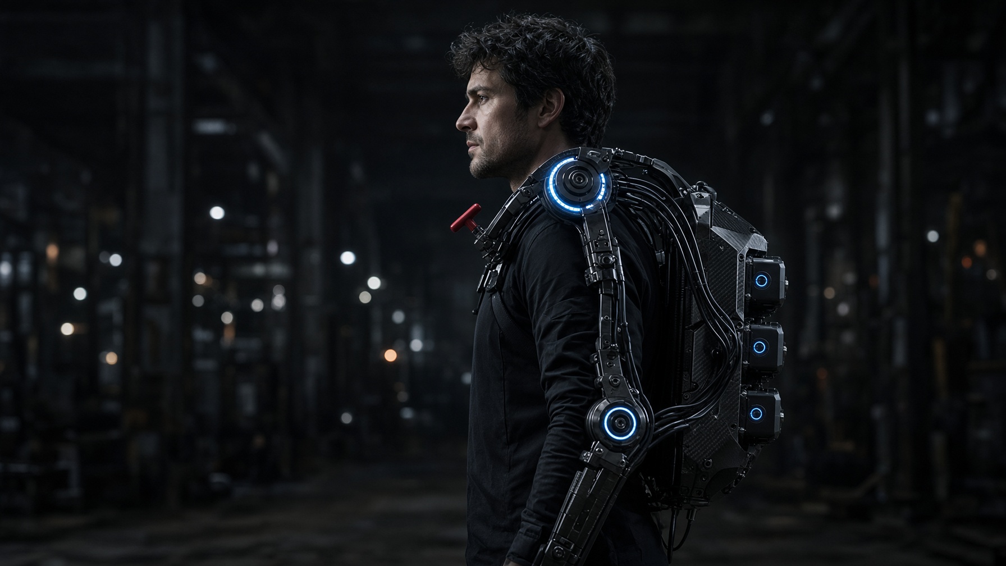
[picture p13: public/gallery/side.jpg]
Side view — three axes


| Operator view | Pack internals |
|---|---|
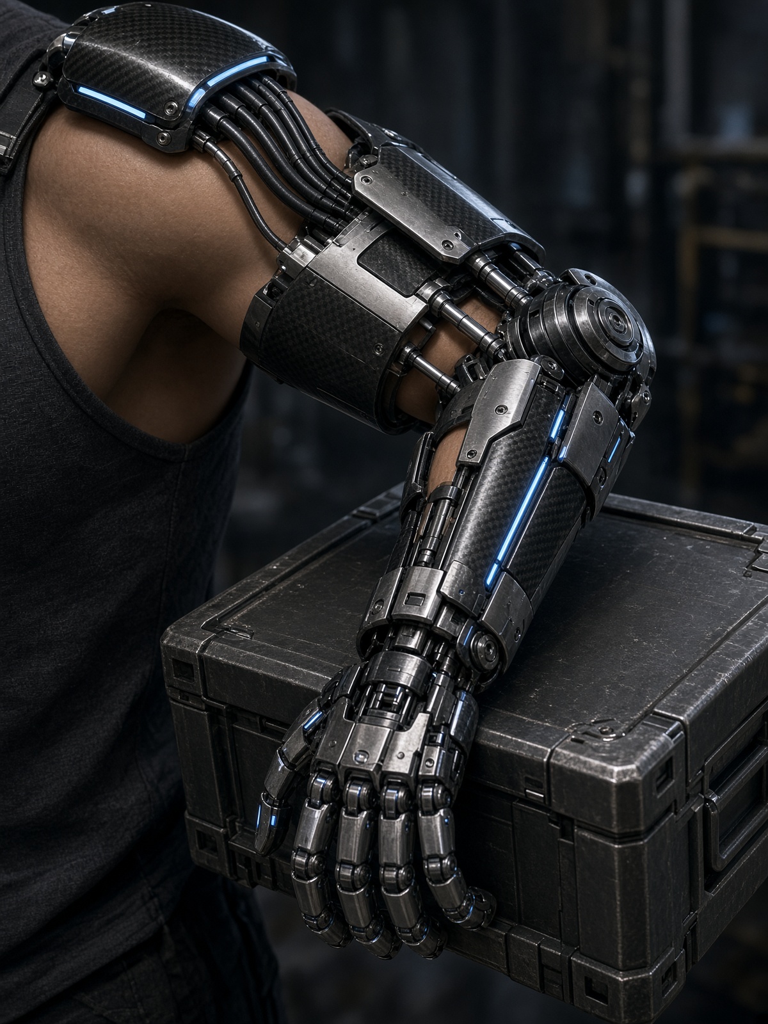
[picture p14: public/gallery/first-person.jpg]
Looking down the armored arm
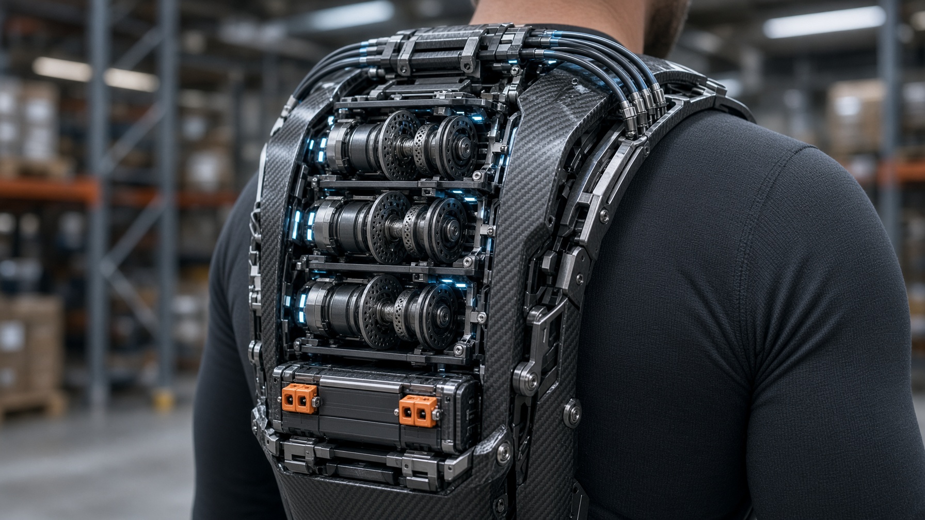
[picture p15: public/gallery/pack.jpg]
Three winch modules in the backpack
|  |  |

| Shoulder pulleys | Elbow antagonist |
|---|---|
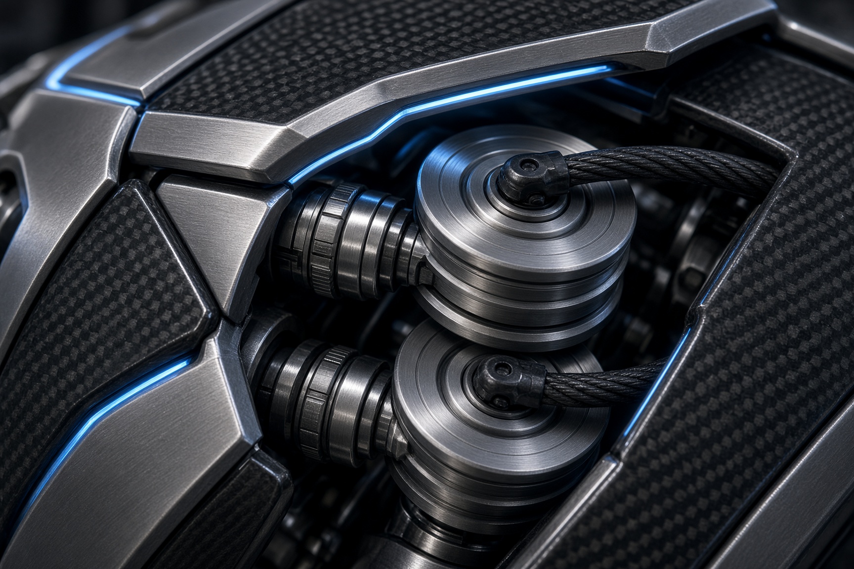
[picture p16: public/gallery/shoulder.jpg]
Shoulder sheaves
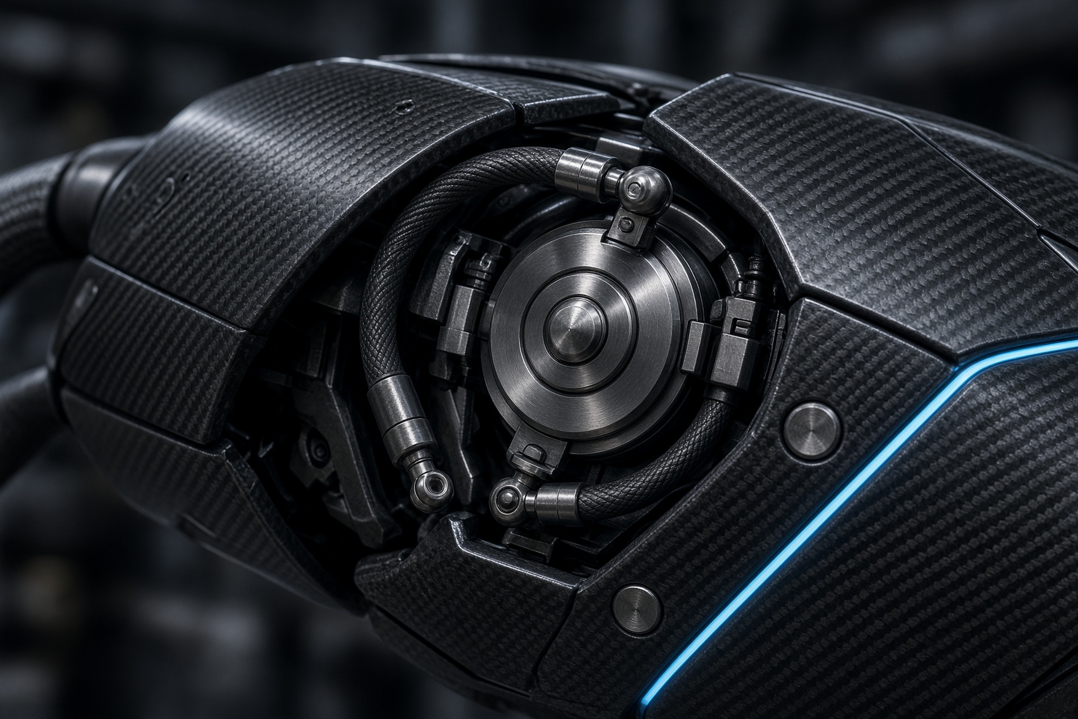
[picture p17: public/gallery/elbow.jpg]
Elbow pulley
|  |  |

| Bench winch | E-stop |
|---|---|
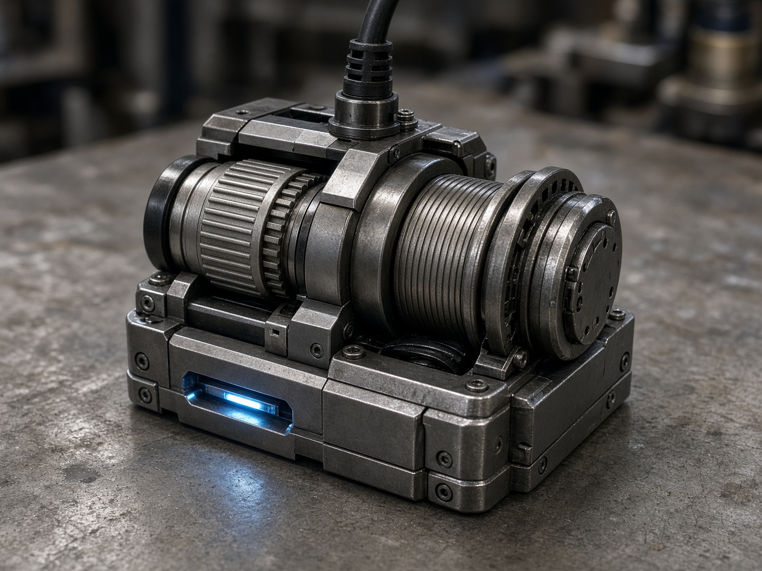
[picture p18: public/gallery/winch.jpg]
Winch module
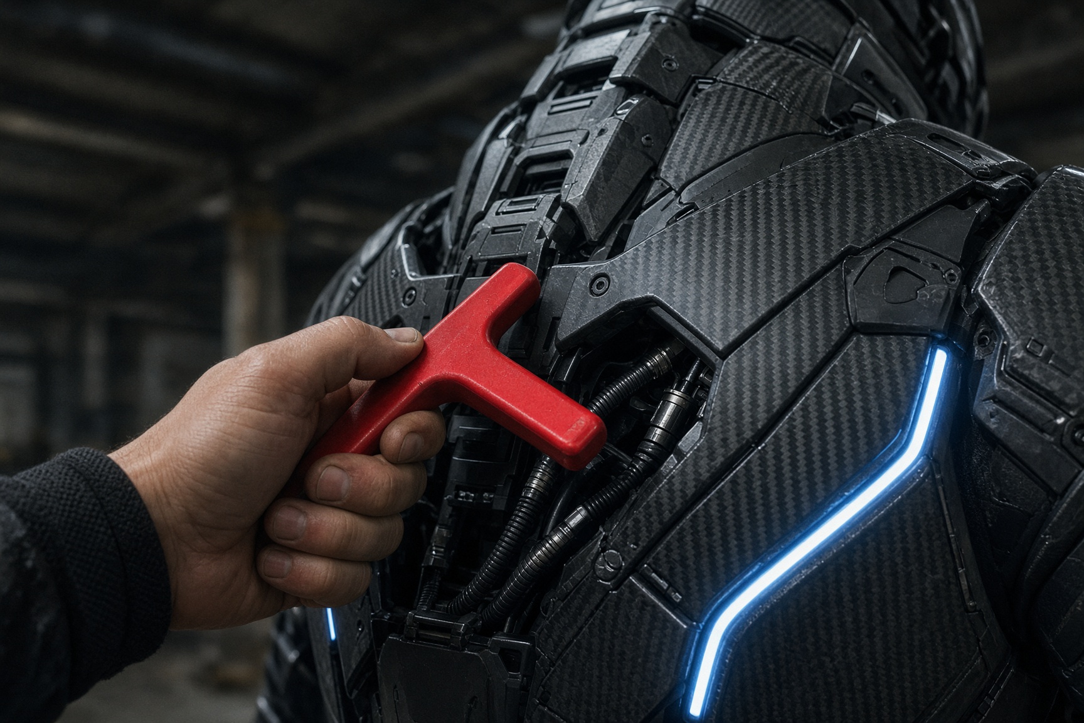
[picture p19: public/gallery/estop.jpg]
Left hand on the red T-handle
|  |  |

## Motion

These clips show the **two lift joints** turning under load. Not a walk-around.

**Coordinated 3R lift** — shoulder flexion, then elbow flexion. Crate from hip to chest. Wrist does not move.

<video src="https://github.com/meetsitaram/cdx-3r/raw/main/public/gallery/lift-3r.mp4" controls muted loop playsinline width="100%"></video>

[Play coordinated lift](https://github.com/meetsitaram/cdx-3r/raw/main/public/gallery/lift-3r.mp4)

**Shoulder flexion** — dual sheaves rotate, cables only pull.

<video src="https://github.com/meetsitaram/cdx-3r/raw/main/public/gallery/shoulder-motion.mp4" controls muted loop playsinline width="100%"></video>

[Play shoulder](https://github.com/meetsitaram/cdx-3r/raw/main/public/gallery/shoulder-motion.mp4)

**Elbow flexion** — antagonist pair wraps the pulley as the forearm closes.

<video src="https://github.com/meetsitaram/cdx-3r/raw/main/public/gallery/elbow-motion.mp4" controls muted loop playsinline width="100%"></video>

[Play elbow](https://github.com/meetsitaram/cdx-3r/raw/main/public/gallery/elbow-motion.mp4)

**Operator view** — looking down the arm as the crate comes up.

<video src="https://github.com/meetsitaram/cdx-3r/raw/main/public/gallery/lift.mp4" controls muted loop playsinline width="100%"></video>

[Play operator view](https://github.com/meetsitaram/cdx-3r/raw/main/public/gallery/lift.mp4)

## Kinematics

Not a 7-DOF industrial arm.

1. Shoulder flexion
2. Shoulder abduction
3. Elbow flexion

## CAD models

Printable plates and cuffs, McMaster sheaves/bearings, pack winches. Open **Build** on the site and tap **Load 3D** to orbit. GitHub itself does not play STLs.

**Full system** — pack on the back, right arm hanging. Saddle takes the exo weight, not the biceps.

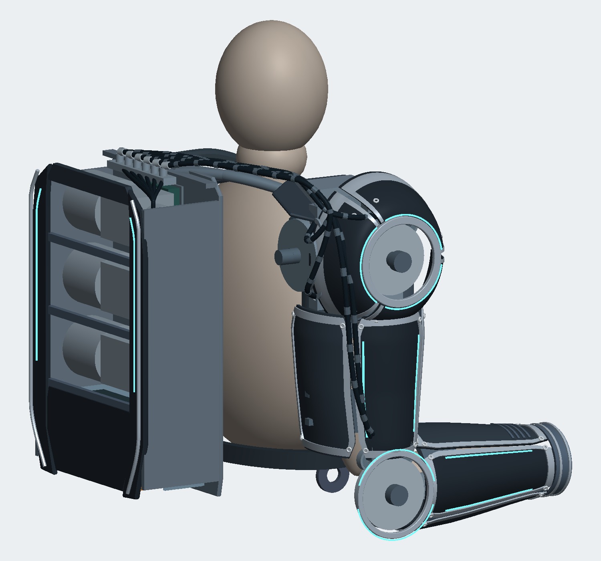
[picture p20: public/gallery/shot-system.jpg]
Full CDX-3R system


**Right arm** — shoulder 2R on top, elbow sheave outboard of the cuffs.

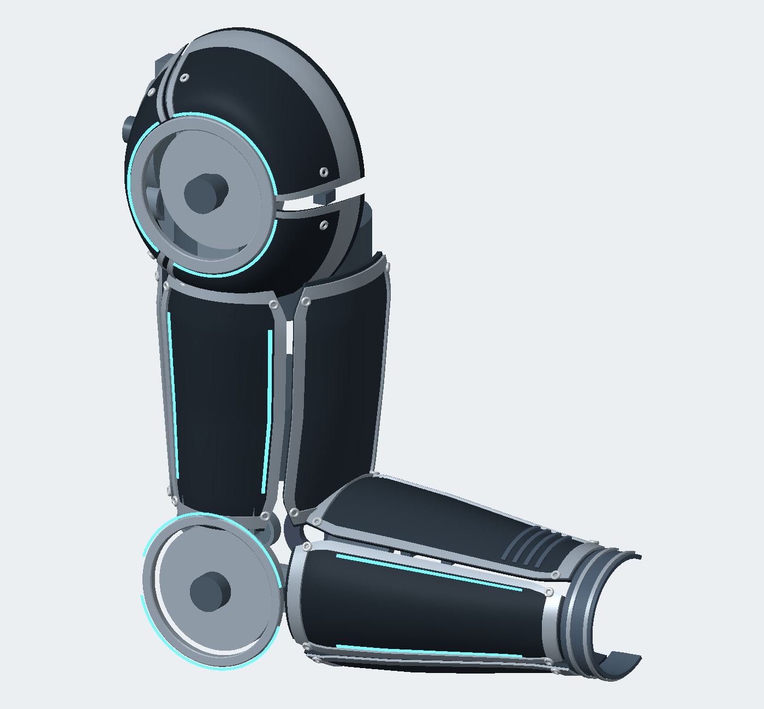
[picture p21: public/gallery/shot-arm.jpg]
Right arm


**Elbow close** — Bowden housing down the upper arm, 608 fairleads, gold 3434T121 sheave.

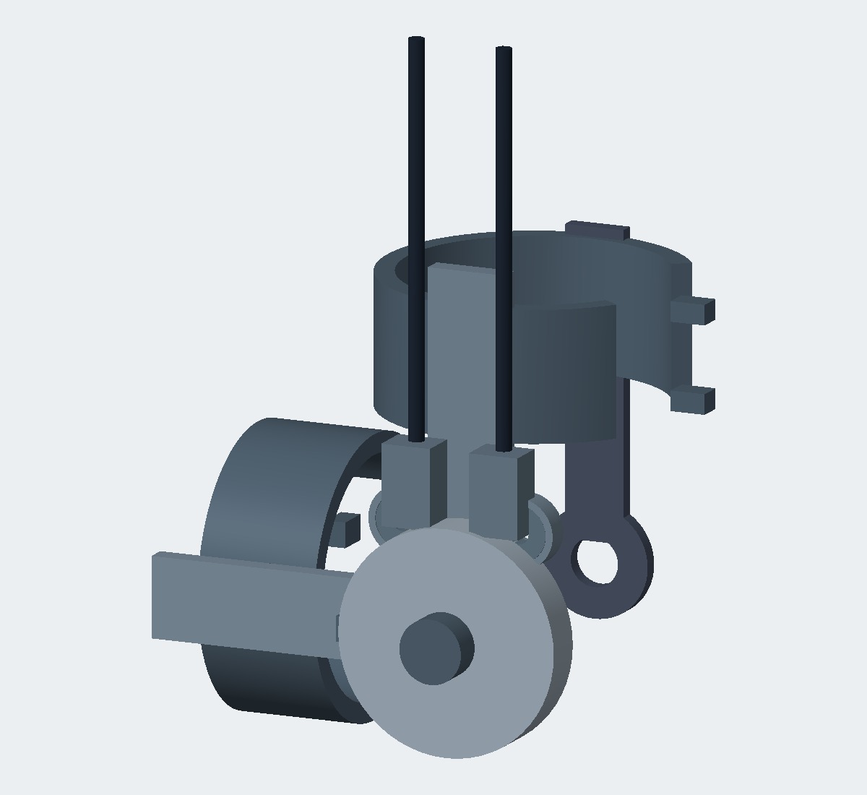
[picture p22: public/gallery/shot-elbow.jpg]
Elbow


Do not print `ref_*_DO_NOT_PRINT.stl`. Buy the McMaster parts.

Folders:

- [cad/README.md](../cad/README.md) — order of work
- [cad/elbow/](../cad/elbow/) — 3434T121 sheave, printable forks/cuffs
- [cad/shoulder/](../cad/shoulder/) — flexion + abduction
- [cad/backpack/](../cad/backpack/) — D6374 + 10:1 + 48 V brick
- [cad/system/](../cad/system/) — saddle, yoke, UA beam, belt, cradle

## Run locally

```bash
npm install
npm run dev
```

Open [http://localhost:8080](http://localhost:8080).

```bash
npm run build
```

## Layout

| Path | What |
|---|---|
| `src/routes/index.tsx` | The site |
| `src/lib/cdx.ts` | Specs, gallery, BOM, cost tiers |
| `public/gallery/` | Stills and motion clips |
| `public/cad/` | STL + preview stills |

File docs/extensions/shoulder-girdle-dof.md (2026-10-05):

# Extension: shoulder-girdle degree of freedom (parked)

Status: **parked** (2026-09-30). The current exo has three joints: shoulder abduction, shoulder flexion and
elbow flexion. This note records the missing fourth one so it can be picked up later.

## Problem

Both shoulder hinges assume the shoulder joint centre (GH) is fixed relative to the back frame. The real GH
moves with the shoulder blade:

- **forward / back** (protraction / retraction): roughly ±30–40 mm;
- **up** when shrugging (elevation): about 40 mm.

With a rigid frame the exo blocks this motion, or pushes on the arm when the wearer moves the shoulder.

## What doesn't work

A slider along the **yoke arc** does nothing: the arc is centred on GH, so sliding along it only moves the flexion
hinge around the same point. The whole shoulder mechanism (mount block, abduction hinge, yoke, link, arm) has
to move relative to the frame.

A **vertical-axis swing joint behind the back** moves GH mostly sideways, not forward (15° of swing):

| Pivot location | GH forward | GH sideways |
|---|---|---|
| Behind the back, near the spine | 29 mm | 53 mm |
| Behind the shoulder blade | 6 mm | 48 mm |
| Above the trapezius, beside the neck | 38 mm | 5 mm |

## Options

**B. Linear slide at the mount block (preferred).** The mount block rides forward/back about ±40 mm on a guide,
re-centred by elastic cord or springs, with soft stops. The guide must carry the tipping moments from the arm
(about 30 N·m when assisting, twice that with bumps):

- twin 10 mm steel rods about 60 mm apart with 4 × LM10UU linear bearings (cheap, robust), or
- an MGN15 rail and carriage (compact; check its moment rating against the datasheet).

It can be motorized later with a small belt or lead screw along the slide. As a passive joint it doesn't
fight the assist, because the lifting loads act across the slide, not along it.

**A. Vertical pivot beside the neck, above the trapezius.** It gives the right motion (it's where the shoulder
blade actually pivots), but needs a boom over the shoulder from the frame, with the whole arm mechanism hanging
from it, next to the neck and the shoulder straps.

**Later: elevation (shrug).** A second passive joint for vertical motion, only if the shrug is felt to be blocked.

## Constraints when implementing

- The **flexion-hinge interface is frozen**: the upper-arm link is already printed. Keep the yoke's 6808 pockets,
  the Ø40 sleeve, the 25 mm housing width with its r44 / r31 step, the 2 mm running gaps to the fork, and the
  M8 × 55 with its captured nut.
- Only the mount block, the yoke root and the frame beams/diagonals change.
- Re-run the clearance and shoulder range-of-motion checks (`cad/scan/tools/check_fusion.py`) over the slide's
  travel.

## Related: abduction-hinge load path (to do regardless)

From the beam check (`cad/scan/tools/yoke_fea.py`):

- The yoke itself is stiff at rest (tip sag 0.4 mm with the arm resting in it). When assisting, the root
  stress reaches about 19 MPa with bumps, across the print layers.
- The abduction bearings (2 × 6806, about ±400 N when assisting) are fine. The weak link is the separate sleeve
  plus the M8: the yoke root sits in front of the front bearing and hands about 28 N·m of tipping moment through a loose sleeve fit.
- Fixes: make the sleeve part of the yoke (a Ø30 tube through both bearings); widen the bearing spacing
  (69 → about 90 mm; optionally 6808s); taper the yoke root 36 → 56 mm tall; print the yoke flat.

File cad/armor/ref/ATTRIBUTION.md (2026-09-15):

# Reference stills

- `harlal-frame.jpg` — thumbnail of
  [power-armor-frame-fallout-4](https://sketchfab.com/3d-models/power-armor-frame-fallout-4-a058d56d197548538514a15d203ed9eb)
  by harlal, [CC BY 4.0](https://creativecommons.org/licenses/by/4.0/).
  Sketchfab download of the mesh requires a login; the mesh is **not** in this
  repo. Used as a topology reminder: frame vs plating, circular shoulder pivot
  left open.

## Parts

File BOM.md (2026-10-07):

# CDX-3R bill of materials: parts to buy

This is for one right arm (elbow concept B) plus the shoulder and back system, as of 2026-09-29. Quantities come
from the current CAD: `cad/fusion/concepts.py` (elbow) and `cad/fusion/shoulder.py` (shoulder + back). Print
details are in `prints/elbow-test-v10/` and `prints/shoulder-back-v2/`.
The last column is what a future **left arm** would add; the frame and harness are shared.

Buy extra of the small parts (see the fastener notes).

## Bearings

| | Item | Spec | Right arm + back | Where | + Left arm | Buy |
|---|---|---|---|---|---|---|
|  | Deep-groove ball bearing | **6806-2RS**, 30 × 42 × 7 mm, sealed | **4** | elbow 2 (upper-arm housings); shoulder abduction 2 (right mount block) | 4 | [uxcell 6806-2RS, 2-pack](https://www.amazon.com/uxcell-6806-2RS-Bearing-30x42x7mm-Bearings/dp/B07TV2HVZ3) |
|  | Deep-groove ball bearing | **6808-2RS**, 40 × 52 × 7 mm, sealed | **2** | shoulder flexion (yoke housing: the shoulder carries the whole arm) | 2 | [XIKE 6808-2RS 40 × 52 × 7, 10 pcs](https://www.amazon.com/XIKE-6808-2RS-Bearings-40x52x7mm-Pre-Lubricated/dp/B09D2VY3BK) |

## Fasteners

**Small screws are two kinds:** **M3 × 8 socket head** machine screws into M3 heat-set inserts, and **#4 × 3/8" pan-head
self-tapping screws** straight into the PVC pipes. Where a wall is thicker, the head sits in a Ø6.5 counterbore, so the
screw always reaches. The two hinge bolts are M8 socket heads.

| | Item | Spec | Qty | Where | + Left arm | Buy |
|---|---|---|---|---|---|---|
|  | Socket head cap screw | **M3 × 8** (ISO 4762), 304 stainless | **26** | into M3 inserts: elbow axles 6 (heads 4.2 mm deep in the axle), elbow covers 12, bottom-node splice channel 8 (2 mm counterbores) | 18 | [Fgruh 720 pcs M3 kit, M3 × 6–30 (has 25 × M3 × 8: use one M3 × 10 for the 26th)](https://www.amazon.com/dp/B0FG2BRXL3) |
|  | Heat-set insert | **ruthex RX-M3 × 5.7**, brass, Ø4.0 hole | **26** | elbow: 6 in the forearm hubs, 12 around the housings; splice: 8 in the bottom-node halves | 18 | [ruthex M3 × 5.7, 100 pcs](https://www.amazon.com/dp/B08BCRZZS3) |
|  | Self-tapping pan-head screw | **#4 × 3/8"** (2.9 × 9.5 mm), Phillips, 304 stainless, pointed | **48** | into the PVC pipes: elbow 18, link pipe head 6, frame 24 | 24 | [#4 × 3/8" Phillips pan head self-tapping, 304 stainless black oxide, 100 pcs](https://www.amazon.com/Phillips-Self-Tapping-Stainless-Corrosion-Resistant/dp/B0F9FP5DV4) |
|  | Socket head cap screw | **M8 × 100** (ISO 4762 / DIN 912, head Ø13 × 8), 304 stainless. **Not flat/countersunk head**: it sits in a flat Ø14.5 counterbore | 1 | shoulder abduction hinge: yoke root → sleeve through both bearings → washer + nut behind the mount block | 1 | [YIIFLY M8-1.25 × 100 socket head cap screws, 304 (A2-70), 8 pcs](https://www.amazon.com/YIIFLY-M8x1-25-Stainless-Machine-Quantity/dp/B0G6YVL3SZ) |
|  | Socket head cap screw | **M8 × 55** (ISO 4762 / DIN 912, head Ø13 × 8), 304 stainless. M8 × 50 is too short (the clamp stack is 52.5 mm) | 1 | shoulder flexion hinge: through the printed Ø40 sleeve in the 6808s; head sunk flush on the arm side of the link fork, nut captured in the outer plate | 1 | [M8-1.25 × 55 socket head, 304 stainless, 10 pcs](https://www.amazon.com/M8-1-25-Socket-Screws-Stainless-Machine/dp/B07L346K4H) |
|  | Nyloc nut | **M8-1.25**, nylon-insert lock nut (DIN 985, 13 mm AF × ~8 mm), 304 stainless | 2 | flexion: drops into the 8 mm hex pocket in the link (can't turn); abduction: behind the mount block, on the fender washer | 2 | [Vifmy M8-1.25 nyloc, 304 (A2-70), 90 pcs](https://www.amazon.com/Vifmy-M8-1-25mm-Locknuts-Stainless-Standard/dp/B0CPJH281Y) |
|  | Fender washer | M8, **32 mm OD** × 1.2 mm, 304 stainless. **Not 30 mm**: a 30 mm washer is the same size as the 6806 bore and slips into the bearing. Over 33 mm it rubs the bearing's fixed outer ring | 1 | behind the abduction mount block, under the nyloc: clamps the rear 6806 inner ring and the sleeve end | 1 | [M8 × 32 mm OD fender washer, 304, 1.2 mm, 50 pcs](https://www.amazon.com/dp/B0GSLW9F7G) |
|  | Dowel pin | **Ø4 × 25 mm**, 304 stainless | 1 | elbow: wrist-cuff hinge (inner side), through the 25 mm knuckle stack (Ø4.2 bores); a drop of CA glue at one end so it cannot slide out (or use an M4 × 30 + nyloc instead) | 1 | [uxcell 4 × 25 mm dowel pin, 304, chamfered ends, 10 pcs](https://www.amazon.com/uxcell-Stainless-Chamfered-Support-Elements/dp/B0BCFKNDMQ) |
|  | Neodymium magnet | **Ø10 × 2 mm** round | 4 | elbow: wrist-cuff latch side (**design pending**: a magnet-assisted snap latch will replace the old quick-release pin; the Ø5.2 latch holes in the current `05`/`06` are not used) | 4 | [Neodymium magnets Ø10 × 2 mm, 100 pcs](https://www.amazon.com/dp/B0FBR9Z39L) |

**Pipe screws:** seat the pipe, then drive the #4 self-tapping screw through the Ø3.2 hole. The printed hole centres
the point, and the screw cuts its own thread in the PVC, usually with no pilot needed. If one skates on the round pipe,
drill a 2 mm pilot through the hole. Snug is enough: over-tightening strips the thin pipe wall. 3/8" is the right
length: about 7 mm of plastic + PVC wall before the thread bites, and the tip ends inside the hollow pipe.

**Inserts:** all insert holes are Ø4.0 × 7 mm deep for the ruthex RX-M3 × 5.7 (elbow v10, shoulder-back v2). Parts
already printed from elbow v9 have 5.5 mm holes: press the insert flush (or run a 4 mm drill to ~7 mm first), and use
**M3 × 10** in the v9 axles.

## PVC pipe (21.5 mm OD / 15.5 mm ID)

| Piece | Cut length | Qty | Where |
|---|---|---|---|
| Upper-arm pipe | 127 mm | 3 | elbow near ring → upper-arm link pipe head |
| Forearm pipe | 185 mm (leans 5.9° toward the wrist) | 3 | elbow near ring → wrist ring |
| Backbone | 412 mm | 2 | bottom node → top node (ends flush inside it) |
| Upper beam | 102 mm | 2 | top node → mount block (L + R) |
| Diagonal | 131 mm | 2 | mid node → mount block (L + R) |

The total is about 2.23 m; **buy 3 m** (cuts plus saw kerf and spares). A left arm adds 3 × 127 + 3 × 185 mm.

## Harness (camping-pack style)

**One webbing size: 1" (25.4 mm)** everywhere. All six strap tabs on the frame have 26 mm slots. Tri-glides adjust length like ladder-locks.

| | Item | Spec | Qty used | Where | Buy |
|---|---|---|---|---|---|
|  | 1" strap kit | 25 mm (1") nylon webbing + side-release buckles + tri-glides | ~3.7 m webbing (6 yd in the kit), 2 buckles, 3 tri-glides | 2 shoulder straps (top tabs → over the shoulders → under the arms → bottom tabs), sternum strap, waist strap (through the two side tabs, buckled at the front) | [BEYOURD 1" set: 6 yd, 6 buckles, 12 tri-glides](https://www.amazon.com/BEYOURD-Buckles-Straps-Set-Adjustable/dp/B08LD8CJ8D) |
|  | Strap pads *(optional)* | slip-on / hook-and-loop strap covers for 1" webbing (e.g. car-seat or backpack shoulder-strap pads) | 2–3 | shoulder straps, waist strap | |
|  | Hook-and-loop strap *(optional)* | 25 mm | ~1 m | arm retention across the open front of the pipe head / rings | |
|  | Foam padding *(optional)* | thin closed-cell, self-adhesive | small sheet | skin-side faces of the arm rings / pipe head, if they rub | |

## Filament

| Item | Qty | Notes |
|---|---|---|
| PETG | ~3 kg | shoulder + back ~2.1 kg (60 % effective fill), elbow set ~0.6 kg, plus fit coupons and reprints |

## Not included yet

- Actuation and power (motors, winches, cables, battery, controller): the back pack is still a placeholder box.
  The battery should sit at the left mount block to balance the right arm (see `prints/shoulder-back-v2/README.md`).
- Shoulder hard stops (abduction 60°, flexion −20 / 120°): not modelled yet; they may add small screws.

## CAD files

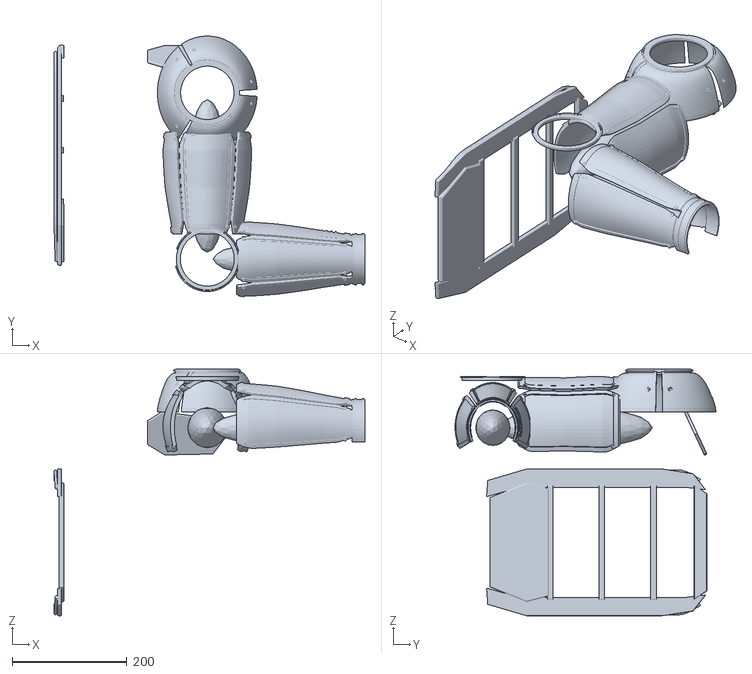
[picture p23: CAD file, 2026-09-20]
cad/armor/stl/assembly_worn.stl
542.4 x 455.0 x 430.0

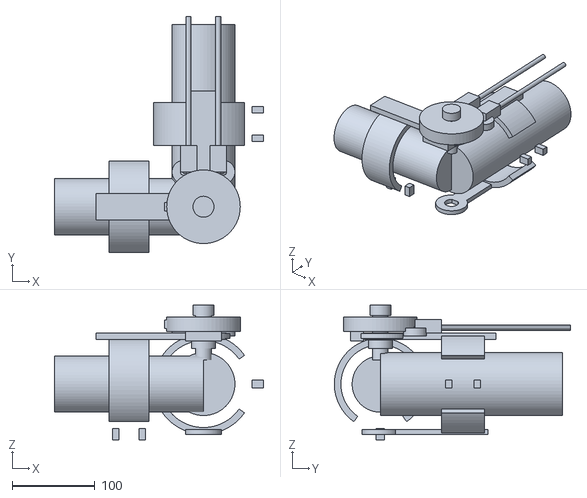
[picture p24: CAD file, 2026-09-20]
cad/elbow/stl/assembly_worn.stl
252.5 x 285.5 x 163.0

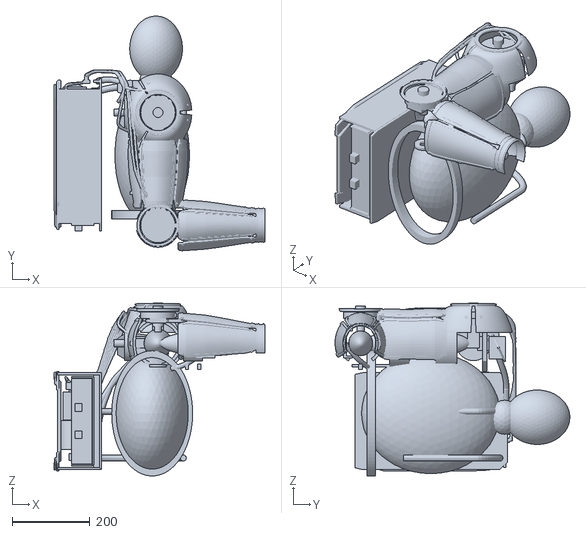
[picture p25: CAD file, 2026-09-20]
cad/system/stl/assembly_worn.stl
542.4 x 604.0 x 444.6

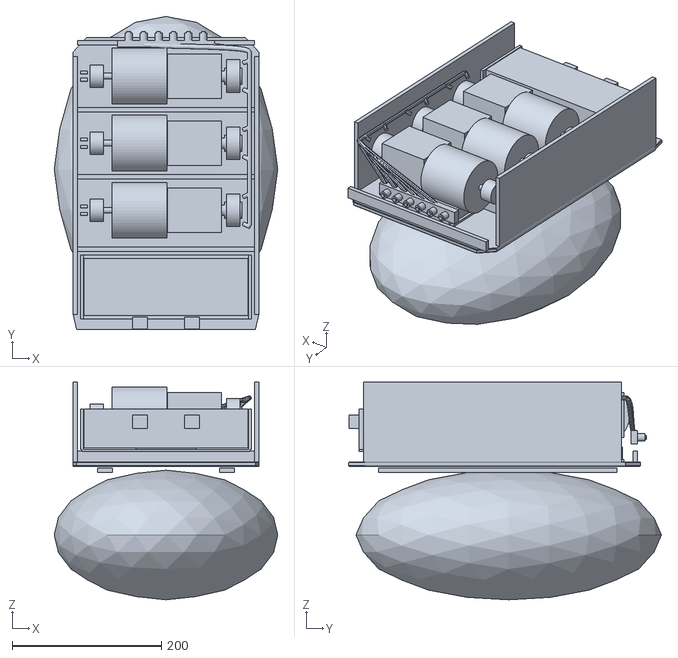
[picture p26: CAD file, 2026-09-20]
public/cad/backpack/assembly_worn.stl
300.0 x 420.0 x 292.0

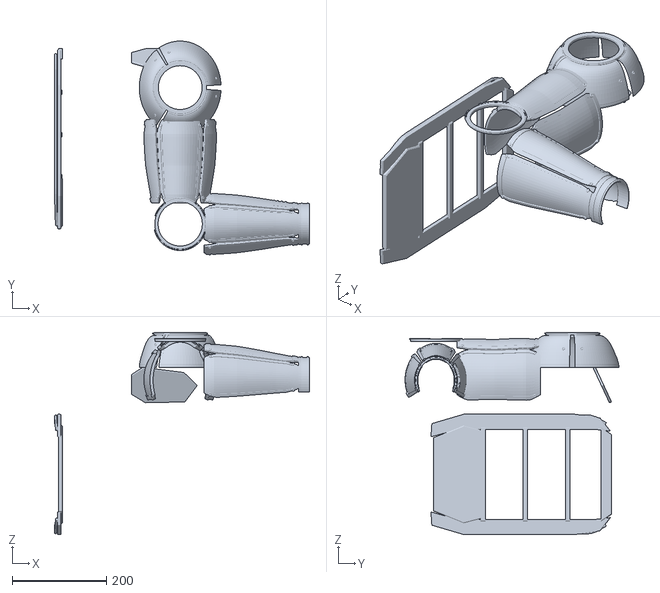
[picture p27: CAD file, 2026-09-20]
cad/armor/stl/assembly_preview.stl
542.4 x 455.0 x 430.0

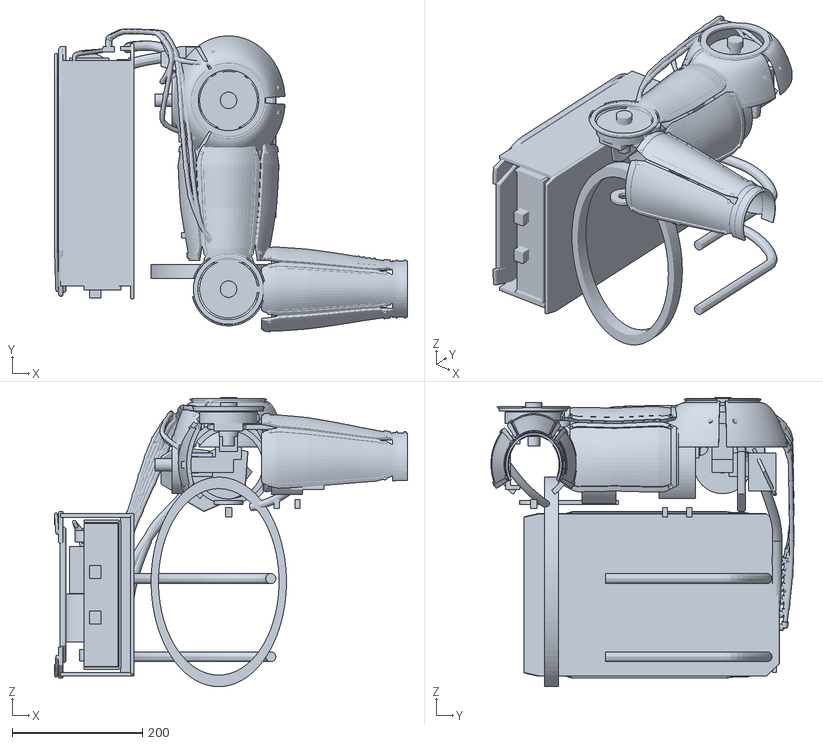
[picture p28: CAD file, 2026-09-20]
cad/system/stl/assembly_preview.stl
542.4 x 465.7 x 444.6

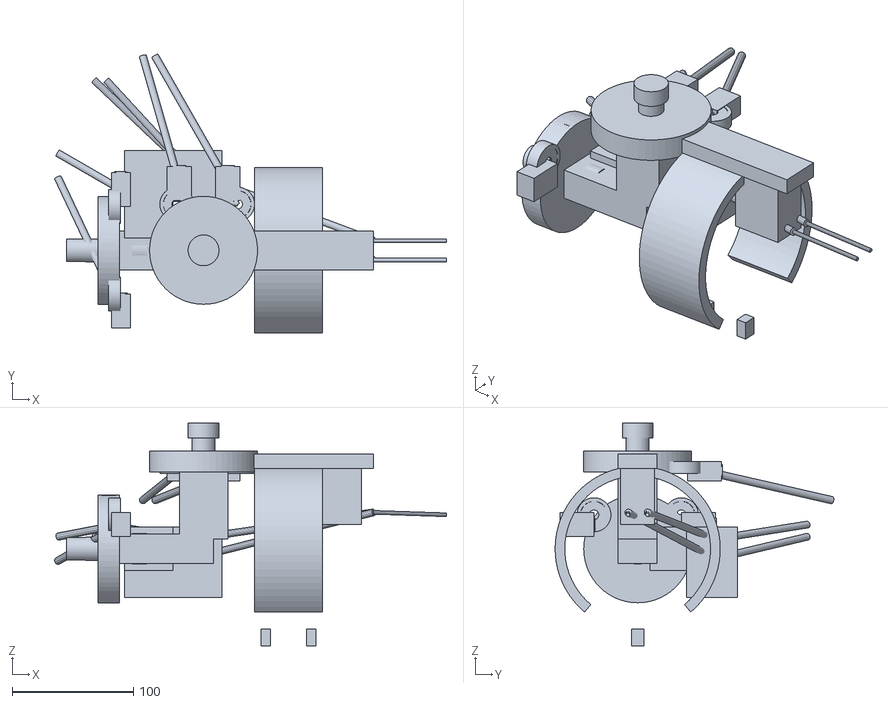
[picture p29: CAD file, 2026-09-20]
public/cad/shoulder/assembly_preview.stl
322.8 x 229.6 x 183.6

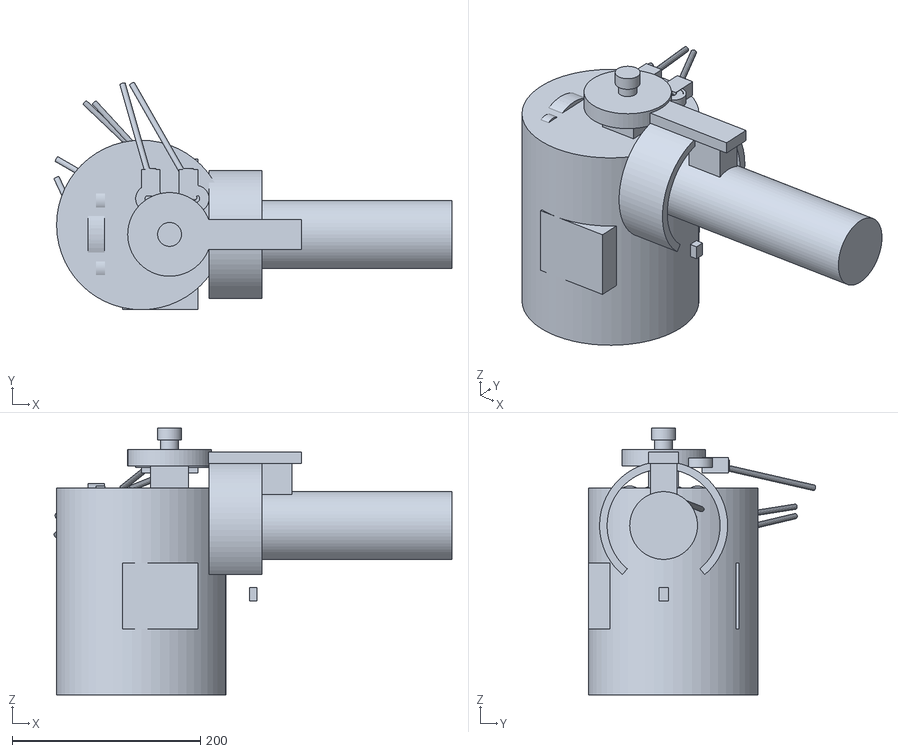
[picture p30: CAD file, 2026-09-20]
cad/shoulder/stl/assembly_worn.stl
422.7 x 241.6 x 283.6

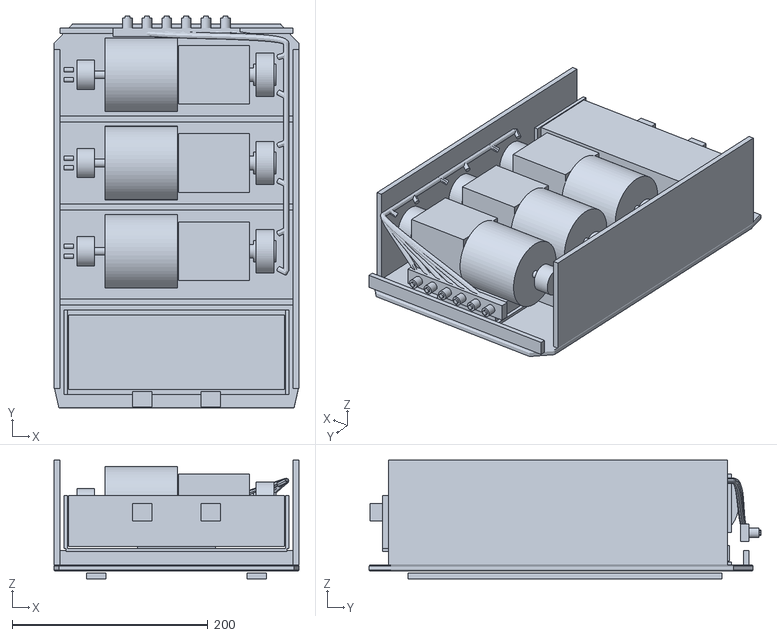
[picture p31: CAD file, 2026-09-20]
public/cad/backpack/assembly_preview.stl
250.0 x 400.0 x 121.0

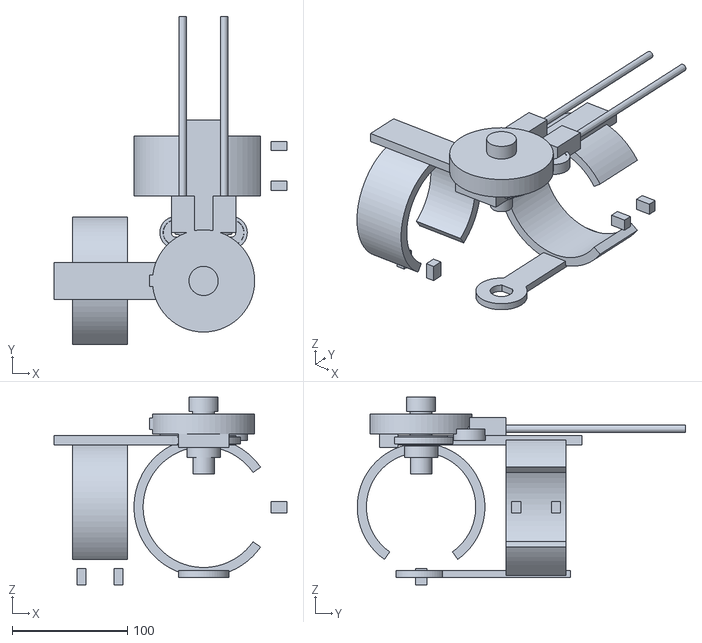
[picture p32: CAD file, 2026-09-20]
cad/elbow/stl/assembly_preview.stl
202.5 x 285.5 x 163.0

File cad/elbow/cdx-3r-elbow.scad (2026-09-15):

// CDX-3R elbow — mm
// part: assembly | fork_l | fork_r | hub | drum | cuff_forearm | cuff_upper | bowden | stop
part = "assembly";

upper_arm_len   = 290;
forearm_len     = 260;
tube_od         = 25;
sheave_od       = 88.9;
sheave_pitch    = 76.2;
sheave_w        = 17.46;
sheave_bore     = 19.05;
shaft_d         = 19.05;
fork_t          = 8;
fork_span       = sheave_w + 14;
cuff_id_fa      = 95;
cuff_id_ua      = 105;
cuff_t          = 8;
insert_m4       = 4.6;

$fn = 48;

module tube(len) {
  difference() {
    cylinder(h=len, d=tube_od, center=true);
    cylinder(h=len+1, d=tube_od-2.4, center=true);
  }
}

module cot_sheave() {
  color("gold") difference() {
    union() {
      cylinder(h=sheave_w, d=sheave_od, center=true);
    }
    cylinder(h=sheave_w+1, d=sheave_bore, center=true);
    rotate_extrude() translate([sheave_pitch/2, 0, 0]) circle(d=6);
  }
}

module print_drum() {
  difference() {
    union() {
      cylinder(h=sheave_w, d=sheave_od-4, center=true);
      translate([0,0, sheave_w/2-2]) cylinder(h=4, d=sheave_od-2, center=true);
      translate([0,0,-sheave_w/2+2]) cylinder(h=4, d=sheave_od-2, center=true);
    }
    cylinder(h=sheave_w+2, d=shaft_d+0.3, center=true);
    rotate_extrude() translate([sheave_pitch/2, 0, 0]) circle(d=5.5);
  }
}

module fork(mirror_z=1) {
  w = 78; h = 58;
  difference() {
    hull() {
      translate([0,0,0]) cylinder(h=fork_t, d=36, center=true);
      translate([-32,0,0]) cube([24, 34, fork_t], center=true);
    }
    cylinder(h=fork_t+1, d=shaft_d+0.3, center=true);
    // 25 mm tube saddle
    translate([-30,0,0]) rotate([0,90,0]) cylinder(h=40, d=tube_od+0.4, center=true);
    // M4 inserts
    for (y=[-12,12]) translate([-38,y,0])
      cylinder(h=fork_t+1, d=insert_m4, center=true);
  }
}

module forearm_hub() {
  difference() {
    union() {
      cylinder(h=12, d=44, center=true);
      translate([28,0,0]) cube([40, 34, 12], center=true);
    }
    cylinder(h=14, d=shaft_d+0.3, center=true);
    translate([30,0,0]) rotate([0,90,0]) cylinder(h=50, d=tube_od+0.4, center=true);
    for (a=[0,90,180,270]) rotate([0,0,a])
      translate([16,0,0]) cylinder(h=14, d=insert_m4, center=true);
  }
}

module cuff(id) {
  od = id + 2*cuff_t;
  difference() {
    cylinder(h=48, d=od, center=true);
    cylinder(h=50, d=id, center=true);
    translate([od/2,0,0]) cube([od, 28, 52], center=true);
  }
  for (z=[-16,16]) for (s=[-1,1])
    translate([s*(id/2+cuff_t+6), 0, z]) difference() {
      cube([14, 10, 8], center=true);
      rotate([90,0,0]) cylinder(h=12, d=6, center=true);
    }
}

module bowden_anchor() {
  difference() {
    cube([28, 18, 16], center=true);
    translate([0,0,0]) rotate([0,90,0]) cylinder(h=30, d=5.3, center=true);
    translate([-8,0,0]) rotate([0,90,0]) cylinder(h=8, d=7.2, center=true); // ferrule
    translate([0,0,0]) cylinder(h=18, d=3.3, center=true); // M3 clamp
  }
}

module hard_stop() {
  difference() {
    cube([30, 18, 14], center=true);
    translate([-8,0,0]) rotate([90,0,0]) cylinder(h=20, d=shaft_d+0.4, center=true);
  }
}

module assembly() {
  color("seagreen") {
    translate([0,0, fork_span/2]) fork();
    translate([0,0,-fork_span/2]) fork();
  }
  cot_sheave();
  color("gray") cylinder(h=100, d=shaft_d, center=true);
  color("silver") {
    translate([-80,0,0]) rotate([0,90,0]) tube(160);
    rotate([90,0,0]) translate([0,0,-80]) tube(160);
  }
  color("seagreen") {
    translate([0, 55, 0]) rotate([90,0,0]) cuff(cuff_id_fa);
    translate([-90,0,0]) rotate([0,90,0]) cuff(cuff_id_ua);
    translate([-40, 28,  20]) bowden_anchor();
    translate([-40, 28, -20]) bowden_anchor();
    translate([18, -28, 0]) hard_stop();
  }
}

if (part=="fork_l") fork();
else if (part=="fork_r") fork();
else if (part=="hub") forearm_hub();
else if (part=="drum") print_drum();
else if (part=="cuff_forearm") cuff(cuff_id_fa);
else if (part=="cuff_upper") cuff(cuff_id_ua);
else if (part=="bowden") bowden_anchor();
else if (part=="stop") hard_stop();
else assembly();

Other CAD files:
cad/armor/stl/asm/bezel.stl
cad/armor/stl/asm/deltoid.stl
cad/armor/stl/asm/deltoid_front.stl
cad/armor/stl/asm/deltoid_rear.stl
cad/armor/stl/asm/elbow_bezel.stl
cad/armor/stl/asm/elbow_led.stl
cad/armor/stl/asm/fa.stl
cad/armor/stl/asm/fa_fasteners.stl
cad/armor/stl/asm/fa_front.stl
cad/armor/stl/asm/fa_led.stl
cad/armor/stl/asm/fa_rear.stl
cad/armor/stl/asm/fa_trim.stl
cad/armor/stl/asm/ghost_fa.stl
cad/armor/stl/asm/ghost_ua.stl
cad/armor/stl/asm/lid.stl
cad/armor/stl/asm/pack.stl
cad/armor/stl/asm/pack_bridge_0.stl
cad/armor/stl/asm/pack_bridge_1.stl
cad/armor/stl/asm/pack_bridge_2.stl
cad/armor/stl/asm/pack_crown.stl
cad/armor/stl/asm/pack_led.stl
cad/armor/stl/asm/pack_right.stl
cad/armor/stl/asm/pack_trim.stl
cad/armor/stl/asm/scapula.stl
cad/armor/stl/asm/shoulder_fasteners.stl
cad/armor/stl/asm/shoulder_led.stl
cad/armor/stl/asm/shoulder_trim.stl
cad/armor/stl/asm/ua.stl
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

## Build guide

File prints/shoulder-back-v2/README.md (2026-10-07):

# Shoulder + back system, print set v2 (Bambu P1S)

This is the back frame, shoulder hinges and upper-arm link, fitted to the exoarm2 body scan. The parts are built by
`cad/fusion/shoulder.py`; the model is `cad/fusion/models/cdx-3r-shoulder-back.f3d` (Fusion document
**CDX-3R shoulder + back**). Every part fits the P1S bed (256 mm). Each STL is one watertight solid, exported in the
design frame, so place it with Lay on Face in Bambu Studio. Bought parts are in `BOM.md` at the repo root.

The left-side frame parts are Fusion mirror features of the right side (the plane is the body midline).

## Parts

| File | Qty | Size (mm) | ~g PETG | Orientation / notes |
|---|---|---|---|---|
| `Upper-arm_link.stl` | 1 | 200 × 164 × 93 | 267 | Outer (spoked) plate flat on the bed. Supports under the round-top inner plate, the curved brace wall and the pipe head. One piece: flexion fork + pipe head + brace wall. |
| `Yoke.stl` | 1 | 197 × 88 × 65 | 154 | Flexion housing axis vertical (round 6808 pockets); support the root boss. |
| `Flexion_axle_sleeve.stl` | 1 | Ø40 × 25 | 23 | On end. Goes through both 6808s. |
| `Abduction_sleeve.stl` | 1 | Ø30 × 69 | 34 | On end. Goes through both 6806s in the right mount block. |
| `Abduction_mount_block_R.stl`, `_L.stl` | 1 + 1 | 150 × 80 × 69 | 426 each | Rear face down (bearing axis vertical). L is empty until there is a left arm (battery mount spot). |
| `Top_node.stl` | 1 | 241 × 70 × 43 | 214 | Back face down; support the two angled beam sockets. |
| `Mid_node.stl` | 1 | 244 × 72 × 39 | 191 | Back face down; support the two angled diagonal sockets. |
| `Bottom_node_R.stl`, `_L.stl` | 1 + 1 | 188 × 92 × 36 | 289 each | Back face down (strap tabs stand up). |
| `Bottom_node_splice_plate.stl` | 1 | 100 × 74 × 42 | 60 | U-channel; open side up. |

The total is about 2.6 kg. Suggested settings: PETG, 0.2 mm layers, 4 walls, 5 top/bottom layers, 40 % gyroid.
Print `prints/elbow-test-v10/00_fit_coupon_bearing_pockets.stl` first if bearing fits are unknown.

## What changed since v1

- The shoulder flexion hinge uses **6808-2RS** bearings with a Ø88 hub (the same size as the elbow). The link is a two-sided fork on an M8 × 55 through-bolt with a printed Ø40 sleeve, and has spoked windows that show the bearing.
- The upper-arm link is one piece: the pipe head (3 blind sockets for the upper-arm PVC pipes, 127 mm long) and
  a curved brace wall up to the link. The link stops the arm swinging back at about −25°.
- The abduction hinge uses a printed Ø30 sleeve through 2 × 6806 and an M8 × 100 through-bolt (no printed axle).
- The bottom-node splice is a U-channel held by 8 × M3 × 8 into M3 heat-set inserts.
- The strap tabs are 10 mm thick, with flared bases.
- Pipe screws: **#4 × 3/8" pan-head self-tapping** through the Ø3.2 holes (Ø6.5 head counterbores where the wall is thick).
- Insert holes (splice) are Ø4.0 × 7 mm deep for **ruthex RX-M3 × 5.7** inserts.
- The load-lifter stays are gone: the backbone pipes (2 × 412 mm) end inside the top node.

## Assembly

1. Heat-set 8 × ruthex M3 × 5.7 inserts (flush) into the bottom-node halves. Bolt on the splice channel (8 × M3 × 8).
2. Push the backbone pipes into the bottom node, then slide on the mid and top nodes. Fit the beams and diagonals to the
   mount blocks. Drive the pipe screws.
3. Press 2 × 6806 into the right mount block. Pass the abduction sleeve through, set the yoke root against the front
   bearing, and fit the M8 × 100 from the yoke side, with the **32 mm** fender washer (not 30 mm: that slips into the 6806 bore) and nyloc behind the block.
4. Press 2 × 6808 into the yoke housing. Fit the flexion sleeve, place the link fork over the housing, drop the nyloc into the
   hex pocket in the outer plate, and fit the M8 × 55 from the arm side.
5. Push the upper-arm pipes (from the elbow's upper-arm piece) into the pipe head sockets and drive 2 screws per pipe.
6. Thread the webbing: the shoulder straps and the waist strap (see `BOM.md`).

## Checks (Fusion + body scan)

- No interference between any bodies, hardware included.
- Flexion running gap 2 mm; abduction running gap 1 mm.
- Rest pose (arm 20° abducted): every part at least 9 mm from the body, except the pipe head's inner face (3.5 mm, like the other
  arm rings).
- Shoulder abduction 20–60° × flexion −20° to 120°: at least 8 mm to the torso and 16 mm to the fixed frame.

## Not in v2 yet

- Dedicated stop pads (abduction 60°; flexion 120° / −25°). The backward stop currently comes from link-to-yoke contact.
- A battery mount on the left block.

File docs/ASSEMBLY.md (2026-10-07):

# How to build the CDX-3R arm exo

This guide walks you through building the exo one small step at a time. Every step has an animation that shows
exactly which part goes where. Watch it first, then do it.

The finished exo

**What you're building:** a backpack-style frame (the *back frame*) with a robot-arm shoulder on the right side. An
arm hangs from the shoulder with an elbow in the middle, and the whole thing is held on with straps. It has 3 joints
that move with your arm: the shoulder lifts your arm sideways, the shoulder swings your arm forward, and the elbow
bends.

**Time:** about 4–6 hours of building (after printing). Do it over a few days if you like. Each big step is a good
place to stop.

> **Grown-up needed** for two jobs: using the **soldering iron** (it gets hot enough to burn) and **cutting the
> PVC pipe** (saw). Everything else you can do yourself.

## Contents

0. [Get ready](#0-get-ready): parts, tools, and 4 skills to practice
1. [Build the elbow](#1-build-the-elbow)
2. [Build the back frame](#2-build-the-back-frame)
3. [Build the shoulder](#3-build-the-shoulder)
4. [Join the arm to the shoulder](#4-join-the-arm-to-the-shoulder)
5. [Add the straps](#5-add-the-straps)
6. [Try it on](#6-try-it-on)

---

## 0. Get ready

### Printed parts

Print everything in PETG. The files are in two folders. Write the **number or name** on each part with a marker as
soon as it comes off the printer, so you don't mix them up.

**Elbow** ([prints/elbow-test-v10](../prints/elbow-test-v10/)):

| ☐ | Part | File |
|---|---|---|
| ☐ | Fit test pieces (print these first!) | `00_fit_coupon_bearing_pockets`, `00_fit_coupon_pipe_holes` |
| ☐ | **01** upper-arm elbow piece | `01_upper_arm_elbow_piece` |
| ☐ | **02** forearm elbow piece | `02_forearm_elbow_piece` |
| ☐ | **03** bearing axle × 2 | `03_bearing_axle_print2` |
| ☐ | **04** round cover × 2 | `04_bearing_cover_print2` |
| ☐ | **05** wrist ring | `05_wrist_ring` |
| ☐ | **06** wrist cuff | `06_wrist_cuff` |

**Shoulder and back** ([prints/shoulder-back-v2](../prints/shoulder-back-v2/)):

| ☐ | Part | File |
|---|---|---|
| ☐ | Bottom node, left half and right half | `Bottom_node_L`, `Bottom_node_R` |
| ☐ | Splice plate | `Bottom_node_splice_plate` |
| ☐ | Middle node | `Mid_node` |
| ☐ | Top node | `Top_node` |
| ☐ | Shoulder blocks, left and right | `Abduction_mount_block_L`, `Abduction_mount_block_R` |
| ☐ | Abduction sleeve (short tube) | `Abduction_sleeve` |
| ☐ | Yoke (the curved arm that goes around your shoulder) | `Yoke` |
| ☐ | Flexion sleeve (wide ring) | `Flexion_axle_sleeve` |
| ☐ | Arm link (the big part with the spoked wheel) | `Upper-arm_link` |

### Bought parts

Links are in [BOM.md](../BOM.md). Put the small parts in separate cups or bags and label them.

| ☐ | Part | How many | What it looks like |
|---|---|---|---|
| ☐ | **6806** bearing (30 mm hole) | 4 | thin steel ring that spins |
| ☐ | **6808** bearing (40 mm hole) | 2 | a slightly bigger ring |
| ☐ | Brass heat-set **insert**, M3 | 26 | tiny brass barrel with ridges |
| ☐ | **M3 × 8** screw (small, hex head) | 26 | small screw, 8 mm long |
| ☐ | **Pipe screw**, #4 × 3/8" (pointed, cross head) | 48 | short pointy screw |
| ☐ | **M8 × 100** bolt (long) | 1 | 10 cm long bolt |
| ☐ | **M8 × 55** bolt (medium) | 1 | 5.5 cm long bolt |
| ☐ | M8 **lock nut** (has a plastic ring inside) | 2 | |
| ☐ | M8 **big washer**, **32 mm** wide (not 30!) | 1 | thin steel disc with a small hole |
| ☐ | **Pin**, 4 mm × 25 mm | 1 | small steel rod |
| ☐ | **PVC pipe**, 21.5 mm outside (½" pipe) | about 2.5 m | |
| ☐ | 1" strap kit (straps, buckles, sliders) | 1 kit | |

### Tools

- soldering iron (any cheap one works; a cone-shaped tip is best)
- hex keys (Allen keys): **2.5 mm** and **6 mm**
- wrench or socket, **13 mm**
- small cross-head screwdriver (Phillips #1)
- saw for the pipe (a hacksaw, or a PVC pipe cutter, which is easier)
- sandpaper
- tape measure or ruler **with millimetres**, and a marker
- super glue (a tiny drop)

### Skill 1: Cutting PVC pipe

1. Measure from the end of the pipe with the **millimetre** side of the ruler and make a mark.
2. Wrap a piece of tape around the pipe right at the mark so you have a straight line to follow.
3. Cut along the tape. Try to keep the cut square, not slanted.
4. Sand off the rough bits (inside and outside the cut) so the pipe slides in smoothly.
5. Write the name of the piece on it.

Being off by 1 mm is fine. If you're in between, cut a little short rather than long.

You'll cut 12 pieces in total. Each step tells you which pieces to cut, right when you need them. Here's the full list
in case you'd rather cut them all at once:

| Piece | Length | How many | Used in |
|---|---|---|---|
| Forearm pipe | **185 mm** (7.28 in) | 3 | step 1 |
| Upper-arm pipe | **127 mm** (5.00 in) | 3 | step 1 |
| Backbone | **412 mm** (16.22 in) | 2 | step 2 |
| Short beam | **102 mm** (4.02 in) | 2 | step 2 |
| Diagonal | **131 mm** (5.16 in) | 2 | step 2 |

That's about 2.2 m of pipe, so 2.5–3 m gives you room for a mistake.

### Skill 2: Melting in a brass insert *(grown-up helps)*

The printed plastic is too soft to hold a screw thread, so you melt a brass insert into it first.

1. Heat the soldering iron to about **225 °C**.
2. Set the insert on top of its hole, narrow end down.
3. Touch the hot tip into the insert and let it sink in **slowly** by itself. Don't push hard.
4. Stop when the top of the insert is **flush** (level) with the plastic. Not deeper.
5. Pull the iron straight up. Let it cool for a minute before you touch it.

Practice on a fit-test piece first!

### Skill 3: Pressing in a bearing

1. Line the bearing up **square** over its pocket.
2. Press it in with your thumbs, pushing on the **outer ring**. If it's tight, put a flat piece of wood on top and
   push with the palm of your hand.
3. It's in when it's flat and doesn't stick up anywhere.

Never hit a bearing with a hammer. Never push on the inner ring when you're pressing the outer ring in.

### Skill 4: Driving a pipe screw

1. Push the pipe all the way into its socket.
2. Put a pipe screw in the small hole and turn it with the screwdriver, so it cuts its own path into the pipe.
3. **Stop as soon as it's snug.** If you keep going, it strips the pipe and won't hold.

Every pipe end that goes into a socket gets **2 pipe screws**.

### First: the fit test

Before printing the big parts, check the two fit-test pieces:

- A **6806 bearing** should press into the test pocket with firm thumb pressure, and stay in.
- A piece of **PVC pipe** should slide into the test hole snugly, with no wobble.

If either one is too loose or too tight, stop and fix the printer settings before you print the big parts.

---

## 1. Build the elbow

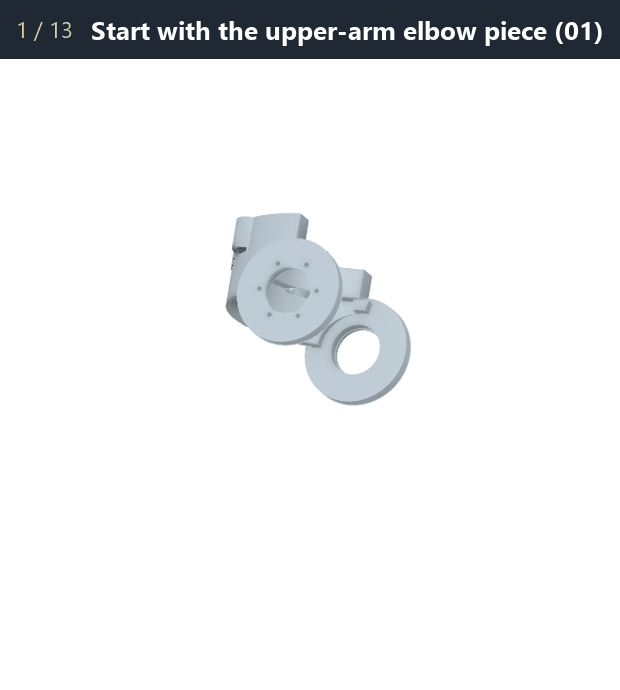
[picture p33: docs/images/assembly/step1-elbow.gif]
Elbow assembly animation


**You need:** parts 01–06, 2 × 6806 bearings, 18 inserts, 18 M3 × 8 screws, 18 pipe screws, the 4 mm pin.

**Cut now:** 3 × **forearm pipe, 185 mm**, and 3 × **upper-arm pipe, 127 mm**.

1. Lay out the **upper-arm elbow piece (01)**.
2. Melt **6 inserts** into the holes around each round bearing hole, on both sides (12 in total). *(Skill 2)*
3. Press a **6806 bearing** into each round hole, from the inside. *(Skill 3)*
4. Slide the **forearm elbow piece (02)** in between the two sides of 01, so its round hubs line up with the
   bearings.
5. Melt **3 inserts** into each forearm hub (6 in total).
6. From the outside, push an **axle (03)** through each bearing until it sits in the hub.
7. Screw each axle down with **3 M3 × 8 screws** (2.5 mm hex key). Snug, not super tight.
8. Put a **round cover (04)** on each side.
9. Screw each cover down with **6 M3 × 8 screws**.
10. Push the 3 **forearm pipes (185 mm)** into the bottom of the elbow. Drive 2 pipe screws into each. *(Skill 4)*
    The pipes lean in a little toward the wrist. That's on purpose.
11. Slide the **wrist ring (05)** onto the other ends of the forearm pipes. Drive 2 pipe screws into each.
12. Put the **wrist cuff (06)** on the wrist ring, line up the little hinge bumps, and push the **4 mm pin**
    through them. Add a tiny drop of super glue at one end so the pin can't slide out.
13. Push the 3 **upper-arm pipes (127 mm)** into the top of the elbow. Drive 2 pipe screws into each.

**✔ Check:** Bend the elbow. It should swing smoothly from straight to a deep bend (135°) and stop by itself at
both ends. Nothing should scrape.

**Note:** The wrist cuff's latch isn't finished yet. For now, hold the cuff closed with a strap.

---

## 2. Build the back frame

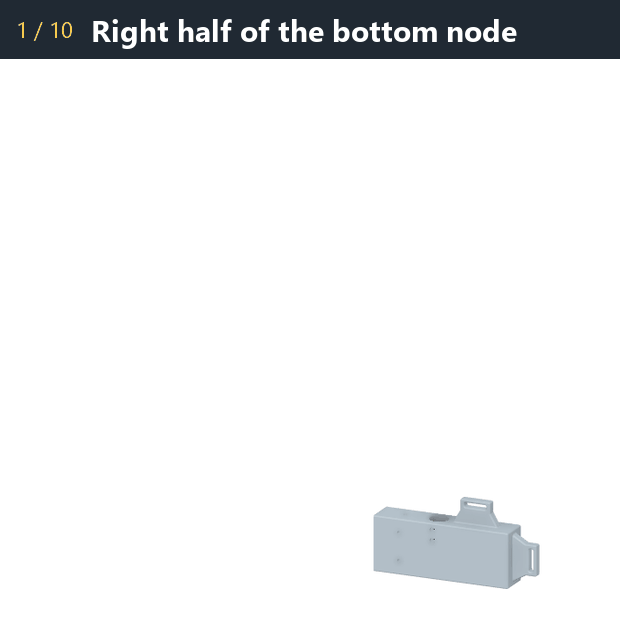
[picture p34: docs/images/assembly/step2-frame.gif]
Back frame assembly animation


**You need:** bottom node L + R, splice plate, middle node, top node, both shoulder blocks, 8 inserts, 8 M3 × 8
screws, 24 pipe screws.

**Cut now:** 2 × **backbone, 412 mm**, 2 × **short beam, 102 mm**, 2 × **diagonal, 131 mm**.

1. Take the **right half** of the bottom node.
2. Put the **left half** next to it.
3. Melt **4 inserts** into each half (8 in total).
4. Lay the **splice plate** over the joint, so it wraps the back, top and bottom.
5. Screw it together with **8 M3 × 8 screws**.
6. Push the 2 **backbones (412 mm)** into the sockets on top of the bottom node. 2 pipe screws each.
7. Slide the **middle node** down over both backbones to its spot. 1 pipe screw per pipe.
8. Push the **top node** onto the top ends of the backbones. 1 pipe screw per pipe.
9. Push the **short beams (102 mm)** into the sides of the top node, and the **diagonals (131 mm)** into the
   sides of the middle node. 2 pipe screws each.
10. Push the **shoulder blocks** onto the outer ends of the beams and diagonals, left and right. 2 pipe screws per
    pipe end.

**✔ Check:** Lift the frame by the top and give it a shake. It should feel stiff, with no loose pipes.

---

## 3. Build the shoulder

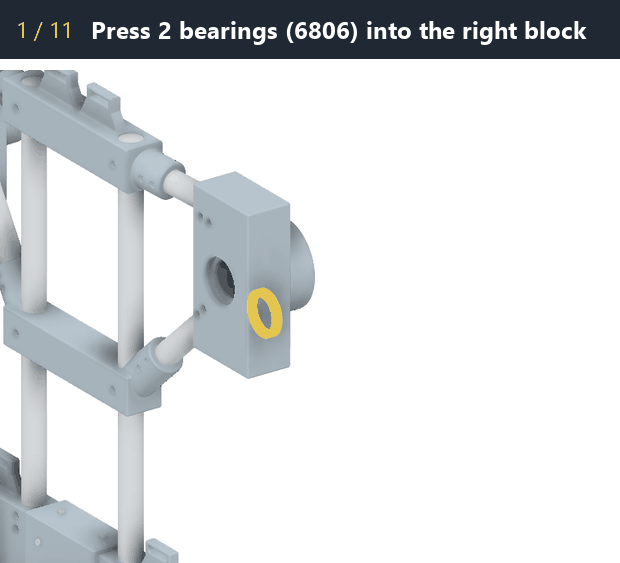
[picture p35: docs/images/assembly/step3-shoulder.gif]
Shoulder assembly animation


**You need:** the frame from step 2, yoke, abduction sleeve, flexion sleeve, arm link, 2 × 6806 bearings,
2 × 6808 bearings, M8 × 100 bolt, M8 × 55 bolt, 2 lock nuts, the big washer (32 mm).

**Part A: the "lift sideways" hinge** (on the right shoulder block)

1. Press a **6806 bearing** into the front pocket and another into the back pocket of the **right shoulder block**.
2. Push the **abduction sleeve** (short tube) through both bearings. Its back end should be **flush** (level)
   with the back bearing. Run a fingernail across: it shouldn't catch.
3. Hold the round end of the **yoke** against the front bearing.
4. Push the **long bolt (M8 × 100)** through the yoke, the sleeve, and out the back.
5. Put the **big washer (32 mm)** on the bolt behind the block. It must rest on the bearing's **inner ring** and
   the sleeve end. If it slides into the bearing hole, it's the wrong washer: a 30 mm washer is exactly the size
   of the hole and falls in. Use the 32 mm one.
6. Screw on a **lock nut**. Hold the bolt with the 6 mm hex key and tighten the nut with the 13 mm wrench until it's
   firm.

**✔ Check:** The yoke swings up and down smoothly, and doesn't wiggle front-to-back.

**Part B: the "swing forward" hinge** (at the end of the yoke)

7. Press a **6808 bearing** (the bigger one) into each side of the round end of the yoke.
8. Push the **flexion sleeve** (wide ring) through both bearings.
9. Drop the second **lock nut** into the 6-sided pocket in the spoked side of the **arm link**. It fits only one
   way and can't turn.
10. Slide the arm link's two sides over the round end of the yoke.
11. Push the **medium bolt (M8 × 55)** in from the other side and tighten it into the nut with the 6 mm hex key.

**✔ Check:** The arm link swings forward and back smoothly. There's a small gap (about 2 mm, the thickness of 2
coins) between the link and the yoke on both sides.

> **Heads up:** a stronger version of the yoke and shoulder blocks is coming (see
> [the extension notes](extensions/shoulder-girdle-dof.md)). If you printed the new version, the steps are the same.

---

## 4. Join the arm to the shoulder

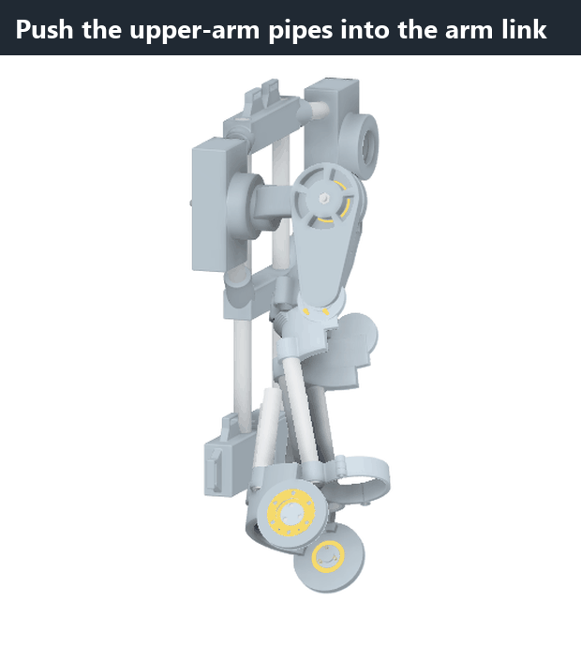
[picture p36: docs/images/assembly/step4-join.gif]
Joining the arm animation


**You need:** the elbow from step 1, the frame + shoulder from step 3, 6 pipe screws. No cutting.

1. Push the top ends of the 3 **upper-arm pipes** into the 3 holes in the bottom of the **arm link**, all the way
   in.
2. Drive **2 pipe screws** into each pipe.

**✔ Check:** Move the arm around slowly:

- lift it out to the side: it should go from about 20° to 60°;
- swing it forward and up: almost straight up (120°), and a little backward;
- bend the elbow: straight to 135°.

Nothing should rub or get stuck.

---

## 5. Add the straps

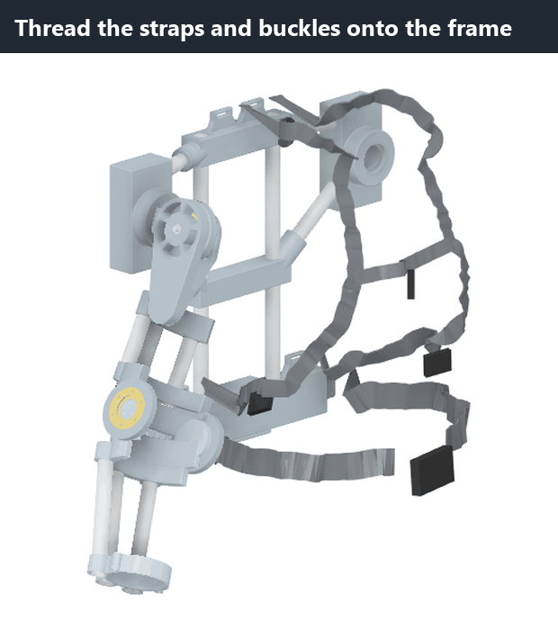
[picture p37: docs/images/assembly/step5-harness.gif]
Straps animation


**You need:** the 1" strap kit (straps, 2 buckles, sliders).

1. **Shoulder straps (2):** tie each strap to a tab on the top node. Bring it over your shoulder, down your chest,
   under your arm, and back to the tab on the bottom node on the same side. Put a slider on it so you can adjust the
   length.
2. **Chest strap:** connect the two shoulder straps across your chest, with a buckle in the middle.
3. **Waist strap:** thread it through the two side tabs on the bottom node, and buckle it in front.
4. *Optional:* slide soft pads (from a backpack or car seat) onto the shoulder straps and waist strap.

---

## 6. Try it on

Get a helper for the first time.

1. Put it on like a backpack: shoulder straps first, then the waist strap, then the chest strap.
2. Tighten the **waist strap** most. The weight should sit on your **hips**, not hang from your shoulders.
3. Put your forearm through the **wrist ring** and close the **wrist cuff**. The arm link should sit at the back and
   outside of your upper arm.
4. Move **slowly**: lift your arm, swing it forward, bend your elbow. If something presses or pinches, stop and note
   where. Small changes in strap length usually fix it.
5. After the first time you wear it, check that the two M8 nuts and all the pipe screws are still tight.

You built an exo!

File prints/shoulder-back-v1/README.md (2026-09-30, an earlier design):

# Shoulder + back system, test print v1 (Bambu P1S)

> **Superseded by `prints/shoulder-back-v2/`.** Kept for history.

Back frame, shoulder hinge mounts and right-arm shoulder mechanism, fitted to the exoarm2 body scan.
Built by `cad/fusion/shoulder.py`; Fusion document **CDX-3R shoulder + back** (project my-projects).
Every part fits the P1S bed (256 × 256 × 256 mm) with at least 11 mm to spare.

Left-side parts are Fusion mirror features of the right side (plane = body midline), so edits to the
right-side features update the left automatically.

## Printed parts

Orient the parts on the plate as listed. The STLs are exported in the design frame, so use Lay on Face in Bambu Studio.

| File | Qty | Size (mm) | ~g | Orientation |
|---|---|---|---|---|
| `Top_node.stl` | 1 | 242 × 70 × 44 | 210 | back face down; support the two angled beam sockets |
| `Mid_node.stl` | 1 | 245 × 73 × 40 | 193 | back face down; support the two angled diagonal sockets |
| `Bottom_node_R.stl`, `Bottom_node_L.stl` | 1 + 1 | 188 × 92 × 36 | 285 each | back face down (strap tabs stand up) |
| `Bottom_node_splice_plate.stl` | 1 | 100 × 56 × 6 | 25 | flat |
| `Abduction_mount_block_R.stl`, `_L.stl` | 1 + 1 | 150 × 80 × 69 | 428 each | rear face down: bearing axis vertical, so the pockets print round |
| `Yoke.stl` | 1 | 190 × 68 × 66 | 133 | flexion-housing axis vertical; support the root boss |
| `Abduction_axle.stl` | 1 | 100 × 50 × 50 | 59 | flange down, shaft up |
| `Upper-arm_link.stl` | 1 | 153 × 56 × 44 | 66 | plate flat, flexion axle up |

Total is about 2.1 kg PETG (the estimate assumes 60 % effective fill). Suggested settings: PETG, 0.2 mm layers, 4 walls,
5 top/bottom layers, 40 % gyroid. The bearing pockets and the axle bore are nominal (Ø42.2 / Ø34 / Ø30);
print a fit coupon from `prints/elbow-test-v9/00_fit_coupon_bearing_pockets.stl` first if the P1S
runs tight.

## Bought parts

| Item | Qty | Notes |
|---|---|---|
| PVC pipe 21.5 OD / 15.5 ID | 2 × 483, 2 × 102, 2 × 131 mm | backbone, upper beam, diagonal (L + R) |
| 6806-2RS bearing (30 × 42 × 7) | 4 | abduction (2, right mount block) + shoulder flexion (2, yoke). The left block stays empty until a left arm |
| M3 × 10 socket head + M3 heat-set insert (Ø4 × 5.5) | 3 | abduction axle flange to yoke |
| M3 × 8 + washer Ø36 (printed or steel) | 2 | axle retainers: abduction axle rear end, flexion axle inner end |
| M4 × 12 + M4 heat-set insert (Ø5.7 × 8) | 4 | splice plate to bottom node halves |
| M4 × 16 | 2 | upper-arm link foot to the far-ring lug (lug not built yet, see below) |
| 25 mm webbing | ~2 m | shoulder straps (top tabs → over shoulder → under arm → bottom tabs) |
| 25 mm ladder-lock | 2 | shoulder strap adjusters |
| 38 mm webbing + 38 mm side-release buckle | ~1.2 m + 1 | waist strap through the two side tabs |

## Assembly

1. Heat-set the M4 inserts in both bottom-node halves. Bolt the splice plate across the seam on the back face.
2. Push the backbone pipes into the bottom node. Slide the mid and top nodes on; the backbone passes through them and
   continues up as the load-lifter stays.
3. Fit the upper beams and diagonals between the nodes and the mount blocks (sockets 25–30 mm deep).
4. Press 2 × 6806 into the right mount block (front and rear pockets). Pass the abduction axle through from the front,
   seat the yoke root in its flange pocket, fit 3 × M3 into the yoke inserts, then fit the rear retainer screw and washer.
5. Press 2 × 6806 into the yoke's flexion housing. Insert the upper-arm link's axle from outside, then fit the inner
   retainer.
6. Thread the webbing: the shoulder straps go from the top tabs over the shoulders and down under the arms to the bottom tabs.
   The waist strap runs through the side tabs and buckles at the front.

## Checks (against the body scan, `exoarm2-scan/tools/check_fusion.py`)

- No interference between any of the 16 bodies (Fusion interference analysis).
- Rest pose (arm 12° abducted): at least 9.7 mm from the body. The closest part is the bottom node at the hips.
- Shoulder abduction 12–60° × flexion −20–120°: at least 10 mm to the torso and at least 19 mm to the fixed frame.
- Centre of mass: about 96 mm right of the spine with the right arm fitted. A battery in or at the left mount block balances it
  (1 kg there brings it to about 24 mm).

## Not in v1 yet

- Hard stops: abduction 60°, flexion −20° / 120°.
- Far-ring lug for the upper-arm link foot (the far ring is in the elbow document).
- Self-tapping screw holes in the pipe sockets (v1 relies on a tight fit or glue).
- Lighter mount blocks (hollow + ribbed, about −200 g each).
- The rigid shoulder rest was dropped: the backpack straps and hip belt carry the frame
  (the STL is kept at `exoarm2-scan/out/print`).

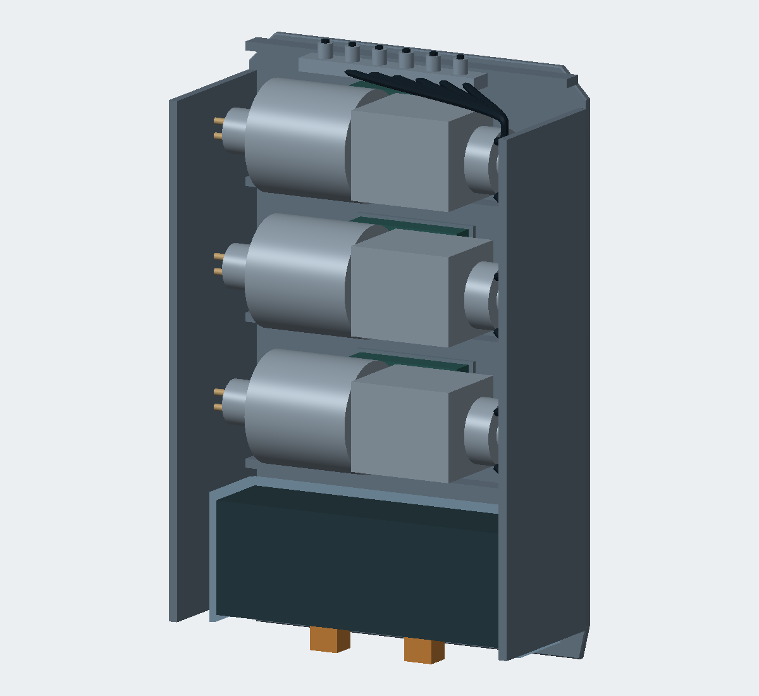
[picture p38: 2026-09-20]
cad/backpack/preview/assembly.png

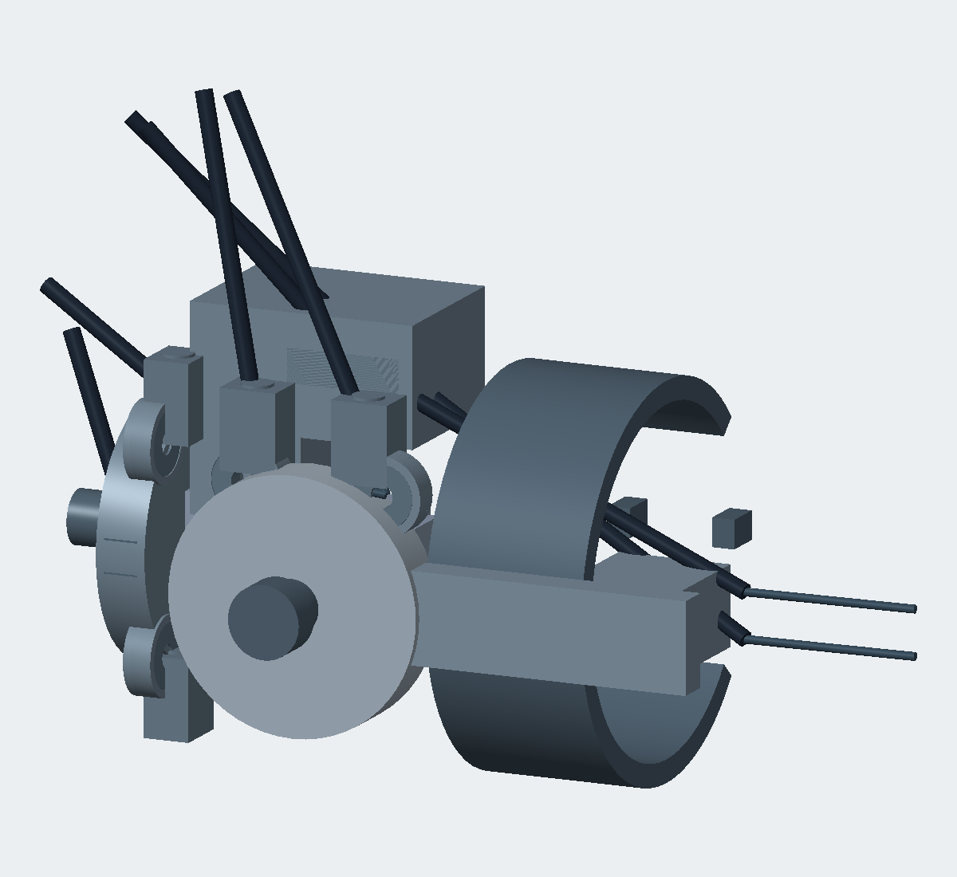
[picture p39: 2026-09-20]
public/cad/shoulder/preview/assembly.png

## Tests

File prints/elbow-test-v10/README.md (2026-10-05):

# Elbow test print v10

This is elbow concept B, built by `cad/fusion/concepts.py` (model `cad/fusion/models/cdx-3r-elbow-concepts.f3d`). Hardware
is in `BOM.md` at the repo root. It pairs with `prints/shoulder-back-v2/`.

## Changes since v9

- **The upper-arm far ring (`07`) is removed.** The upper-arm pipes now run from the elbow's near ring straight into the
  pipe head on the shoulder's upper-arm link. The upper-arm pipes are **127 mm** long (the forearm pipes stay 185 mm).
- **Axles `03`:** the screw heads sit 1 mm deeper, so all small screws are **M3 × 8** (no more M3 × 10).
- **Covers `04`:** spoked, with an open Ø38.5 centre and 6 windows, so the bearing and axle show. They still hold the bearing's outer ring.
- **Insert holes are Ø4.0 × 7 mm deep** for ruthex RX-M3 × 5.7 inserts (forearm hubs `02`, housings `01`).
- Pipe screws: #4 × 3/8" pan-head self-tapping, 2 per joint, through the Ø3.2 holes.
- **Wrist cuff latch (`05`, `06`, +X side):** Ø5.2 holes for a Ø5 × 30 mm ball-lock quick-release pin; the hinge side stays Ø4.2 for the Ø4 × 25 dowel.
- `01`, `02`, `05` and `06` are otherwise unchanged in shape (re-exported). `01` has the same few mesh defects as in v9. Bambu Studio
  repairs them on import; the v9 print was fine.

## Parts

| File | Qty | Notes |
|---|---|---|
| `00_fit_coupon_pipe_holes.stl` / `00_fit_coupon_bearing_pockets.stl` | 1 each | quick fit tests |
| `01_upper_arm_elbow_piece.stl` | 1 | ring face down; tree supports in the bearing pockets |
| `02_forearm_elbow_piece.stl` | 1 | ring face down |
| `03_bearing_axle_print2.stl` | 2 | flat, pilot up; 3 × M3 × 8 each into the forearm hub inserts |
| `04_bearing_cover_print2.stl` | 2 | flat; 6 × M3 × 8 each |
| `05_wrist_ring.stl` | 1 | flat |
| `06_wrist_cuff.stl` | 1 | flat |

Already printed v9? It still works: press the 5.7 mm inserts flush into the 5.5 mm holes (or run a 4 mm drill to
~7 mm first), and use **M3 × 10** in the v9 axles (their head pocket is 1 mm shallower). Reprint `03` and `04` only if
you want the spoked covers and M3 × 8 everywhere. The v9 `07` far ring is no longer used.

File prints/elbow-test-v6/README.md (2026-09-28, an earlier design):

# Elbow test print v6 (current)

Concept B elbow from `cad/fusion/concepts.py`, right arm, all sizes in mm.
Goal: check that the PVC pipes push into the rings and that the elbow turns smoothly on its
two 6806 bearings.

## What's new in v6: axle bolted to the forearm (option A)

- The bearing axle is a flanged stub bolted to the forearm hub, like a wheel on its hub.
  A Ø16 × 3 pilot on the axle drops into a recess in the hub; it centres the axle and takes the
  load in shear. 3 × M4 screws, heads sunk into the axle, clamp it into heat-set inserts in the hub.
- A 0.5 mm shoulder on the axle (Ø32.5) is the only thing touching the bearing, on its inner
  ring. The hub face is relieved 1 mm so it can't rub the outer ring or seal.
- The housing's retaining lip hole is Ø39.5, so it touches only the bearing's outer ring.
- Changed since v5: `01`, `02`, `03`. The others are unchanged apart from re-export.

## 0. Fit coupons first (about 30 min each)

| File | What to try |
|---|---|
| `00_fit_coupon_pipe_holes.stl` | Push a PVC pipe (21.5 OD) into each hole: 21.7 / 21.9 / 22.1 / 22.3, marked 1-4 dots. The parts use **21.9**. |
| `00_fit_coupon_bearing_pockets.stl` | Press a 6806 into each pocket from the top: 41.9 / 42.05 / 42.2, marked 1-3 dots. The parts use **42.05**. |

If another size fits better, say which and the parts get re-exported before the long prints.
In the upper-arm piece the pockets print on their side, so they may come out slightly tighter
than on the coupon.

## 1. Parts

| File | Qty | Print orientation | Notes |
|---|---|---|---|
| `01_upper_arm_elbow_piece.stl` | 1 | Ring face down; the shell rises, bearing housings on top | 160 × 132 × 109. Tree supports inside the two Ø42 pockets only |
| `02_forearm_elbow_piece.stl` | 1 | Ring face down | Rear stop ledge is a 45° staircase: no support needed |
| `03_bearing_axle_print2.stl` | 2 | Flat on its outer face, pilot up | 3 × M4 to the forearm hub |
| `04_bearing_cover_print2.stl` | 2 | Flat | 6 × M3 into the housing |
| `05_wrist_ring.stl` | 1 | Flat | Back half of the wrist ring; 3 leaning pipe holes; cuff knuckles |
| `06_wrist_cuff.stl` | 1 | Flat | Front half; swings open sideways |
| `07_upper_arm_far_ring.stl` | 1 | Flat | Top ring of the upper arm |

Settings: PETG (or ASA), 0.2 mm layers, 5 walls, 5 top/bottom, 40 % gyroid.
The wrist ring's 80 mm bore and the upper arm's 120 mm bore are placeholders until measured.

## 2. Hardware (one elbow)

- 2 × 6806-2RS bearing (30 × 42 × 7)
- 6 × M4 × 12 socket head screws + 6 × M4 heat-set inserts (axles to forearm hub)
- 12 × M3 × 8 screws + 12 × M3 heat-set inserts (covers)
- Wrist cuff: 1 × 4 mm pin about 25 mm (hinge, inner side) + 1 × 4 mm quick-release pin (latch, outer side)
- PVC pipe 21.5 OD: 3 per arm segment

## 3. Assembly

1. Heat-set the inserts: 3 × M4 in each forearm hub face, 6 × M3 around each upper-arm housing.
2. Press a bearing into each upper-arm housing, from the inside face.
3. Set the forearm piece inside the upper-arm piece, hubs just inside the bearings.
4. From outside, push an axle through each bearing so its pilot drops into the hub recess;
   screw it down with 3 × M4.
5. Screw the covers on.
6. Rotate: straight (hard stop at the back, about 1° past straight) to 135° (hard stop at the
   hubs) with no rubbing.
7. Push the pipes through the far rings into the elbow-end rings until they seat in the shell.

## Checks done in Fusion

- Elbow 0-135° and wrist cuff 0-100° (elbow at 0° and 90°): no collisions.
- Pipes: sliding a pipe-sized cylinder along each pipe's axis through both rings meets
  0.0 mm³ of plastic, for all 6 pipes.
- Stops: flexion contact at 135°, hyperextension at about 1° past straight.
- Nothing on the forearm comes within 4.8 mm of the upper arm at full fold.
- Section views in `sections/`.

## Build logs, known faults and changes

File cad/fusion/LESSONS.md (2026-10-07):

# Lessons learned: CDX-3R in Fusion + body scan

These are the issues we hit building the elbow (concept B) and the shoulder + back system on the
exoarm2 body scan, grouped by category. Each entry says what went wrong, why, and what to do instead.
Read this before starting a new part.

## 1. Environment and tooling (Windows PC)

| Issue | Cause | Do instead |
|---|---|---|
| No Python; only the Microsoft Store alias | fresh Windows install | `winget install Python.Python.3.12 --scope user`, then pip: numpy scipy open3d trimesh manifold3d shapely mapbox_earcut scikit-image matplotlib |
| matplotlib `plot_trisurf` crashed: "Application Control policy has blocked" `_qhull` | Windows Application Control blocks that DLL | render with `Poly3DCollection` (`exoarm2-scan/tools/render.py`) |
| Garbled characters (mojibake) in READMEs; a Python edit failed to match "Ø" | PowerShell 5 and Python on Windows default to cp1252 | write text with the Write tool; in Python always `open(..., encoding='utf-8')` |
| `/tmp/x.json` written in bash was not found by Python | Git-Bash `/tmp` and Windows Python resolve to different folders | use project or scratchpad paths |
| Multi-line heredoc edits broke ("here-document delimited by end-of-file") | quoting and special characters inside the Bash tool | write the edit script to a file, then run it; for exact replacements use the Edit tool |
| git not found in PowerShell; push rejected for a private email | git is not on PATH there; GitHub email privacy | use Git Bash; pass `-c user.email=<id>+<user>@users.noreply.github.com`; commit message from a file; GCM browser login |
| Fusion MCP showed `ECONNREFUSED` although Fusion was running | a session connects to MCP servers only at start; Fusion's server was not up yet | start Fusion first and let it load fully. If the connection failed, ask the user to reconnect **fusion** via `/mcp`. Do not write a workaround client |

## 2. Fusion API gotchas

| Issue | Do instead |
|---|---|
| Bounding boxes stale or wrong inside a script (built an elbow backwards; "moved" parts that had not moved) | measure with `measureManager.measureMinimumDistance`, `physicalProperties.centerOfMass` on assembly proxies, or tessellation extents; confirm with a screenshot |
| New occurrences come in grounded, so joints do not move them | set `occ.isGroundToParent = False` on moving parts |
| Joint pose lost after save / in references | after setting `rotationValue`, capture the position with `design.snapshots.add()` before `doc.save()` |
| STL export of an occurrence is in the component's **own** coordinates (parent transforms ignored) | account for it in checks: moving parts arrive un-posed; concept-frame parts need mapping; never guess units from magnitude (a "<400 → cm" rule broke small parts) |
| Inserting a Z-up document into a Y-up one re-orients it; an xref of a design with two **ungrounded** jointed units re-solves unpredictably (arm units lay sideways) | copy the posed bodies with `TemporaryBRepManager.copy(proxy)` into a component with a known transform (`shoulder.place_elbow`); re-run after elbow edits |
| Body names/appearances set inside a base-feature edit were lost | set them after `bf.finishEdit()` |
| A JOIN whose target it doesn't touch silently makes a **new body** (the link came out as 4–6 bodies; loose bosses overlapped pipes) | build outward in connected order (hub → strip → web → head → bosses → fork); assert body count is 1 |
| Feature names get " (1)" appended | match with `startswith` |
| Circular pattern of cut features fails when a copy cuts nothing | drill once at the end; pattern only what intersects |
| Fillet sets fail as a whole | tangent chain off; try the set, then edge-by-edge with a smaller radius, then skip (`concepts._fillet`) |
| Rounding the rim of a Ø51 flange pocket nicked the mating flange (1 mm³) | never round hole/socket/pocket edges; the skip test covers concave cylinders up to r 30 mm |
| Reference meshes drew every triangle edge (no per-body API switch; "Smooth Shaded" doesn't help) | hide the mesh bodies and draw them as **custom graphics** (`shoulder.show_reference_smooth()`); not saved with the document, so re-run it after reopening |
| Rebuilding the frame (`main()`) recreates the top component and wipes the arm side | after `main()` always run `main2()` and `place_elbow()` |
| Five different small screws (M3 × 8/10, M4 × 12, #4 self-tappers) made ordering and assembly painful | pick **one** small screw (M3 × 8) and one insert; counterbore the head wherever a wall is thicker, so the screw always reaches; but into PVC use **#4 × 3/8" pan-head self-tapping screws** (pointed, the common kind): they cut their own thread, and the printed hole centres them |
| A trim cut split a wall into a sliver + the wall; the join grabbed the stale reference (the sliver), leaving the wall loose and uncut by later sockets | after any cut that can split a body, re-collect bodies by volume, drop slivers, join everything; step the timeline (markerPosition) to find which feature changes the body count |
| Plate and gusset of different widths, or a gusset starting mid-disc, left pinch corners | give a disc-plus-plate a D profile: circle on top, a same-width rectangle below (tangent sides); start the slope where the circle ends; keep it thin next to the skin (a flat layer running further down pressed into the deltoid) |
| Insert holes sized for 4 mm inserts; the inserts actually bought were ruthex 5.7 mm | size insert holes from the actual part bought (ruthex RX-M3 × 5.7: Ø4.0 × ~7 mm); model the insert at its real length |
| Mesh bodies in a parametric design | add them inside a base feature (`baseFeatures.add(); startEdit(); meshBodies.add(...); finishEdit()`) |
| Left/right copies drifted when edited separately | build the right half and add a **Mirror feature** about a midline construction plane (associative); for split prints use `isCombine=False` |

## 3. Geometry and modelling mistakes

| Issue | Do instead |
|---|---|
| Renders showed the arm on the wrong side | plotting (X, Z, Y) swaps handedness; plot (X, −Z, Y) and label views from the viewer's side |
| Scan frame vs CAD frame confusion | one documented frame (scan: mm, X fwd, Y up, Z right, floor Y = 0); concept frame X lateral, Y anterior, Z up the upper arm; convert explicitly (`elbow_matrix`) |
| A variable reused (`out`) wiped the parts dict | distinct names for geometry temporaries |
| Zero-length tube segment gave NaN meshes | drop duplicate path points |
| An angled pipe hit the backbone pipe inside the node | socket bottom at `clear_start()` = (OD + gap) / sin(angle) along the pipe |
| An angled pipe's rim dug into the block before its socket began | start the socket cut in the air (−15 mm before the face) |
| A blunt "arm bore" cut through composite parts left fins and knife edges | shape features to stop short (web ends inside the band, bosses stop 0.5 mm short of the bore); no trim cut needed |
| Enclosed voids: an insert hole buried under the yoke band; tunnels in the scan torso | check each STL is one watertight shell with positive volume; count shells |
| A part longer than the P1S bed (376 mm) | check each printed body's oriented box against 256 mm minus a margin; split symmetric parts at the mirror plane plus a bolted splice plate |
| Sharp edges everywhere looked unfinished | `round_edges()` on every printed body (2 mm), skipping fits and the mirror seam |
| Stacked hub + strip + web prisms of different widths left visible steps | derive a part from **one outline** (e.g. hub disc + end disc + tangent lines) and cut every feature from it (extrude, or intersect with a region) so all sides are flush |
| Concentric hinge parts all different radii (r 28 / 34 / 36) looked random | make stacked circles on one axis the same radius; pick the smallest that keeps the wall (r 30 = 9 mm around a 6806) |
| Merged pieces came out separate **again** (the fork's inner plate joined before the Y wedge that connects it) | order every JOIN/combine so each piece touches what is already there; check the body count after each rebuild |
| A straight full-length Y slope came within 1.9 mm of the deltoid; a half-length Y left a ledge | run the gusset the full length and make its inner edge an **arc bowed away from the body** (6 mm sag); end neighbouring slabs exactly where the slope starts |
| A sketch arc + lines made a bow-tie profile (thin strut instead of a solid gusset) | Fusion orders arc ends counter-clockwise, not as given: connect lines to whichever arc end is nearest each point |
| Hardware helper hard-coded an M8 shank, so the M4 screws modelled 4x too big and "collided" | size every bought part from parameters; run interference including '(buy)' bodies |
| Edge rounding also rounded the hex nut pocket's inside corners, so the nut would not fit | cut fit features (hex pockets, counterbores, bearing pockets) **after** `round_edges`, or skip them |
| A final `finish(name)` renamed all hardware bodies to "HW ... 1..n" | never rename '(buy)' components' bodies |
| A 4.4 mm button head on the arm side became the tightest part in the shoulder sweep | sink bolt heads that face the body: low-head DIN 7984 in a counterbore, with the material behind it counted (plate + boss) |
| The abduction hinge's 30 mm fender washer pulled into the rear 6806 (bore 30): it only sat on the sleeve end and clamped nothing | a washer or boss that clamps a bearing inner ring must be **larger than the bore and no larger than the ring land** (6806: 30 < OD ≤ 33, so a 32 mm washer); check bought washers against both, not only the bolt size |
| A combined elbow rebuild + shoulder rebuild in one MCP call timed out | split long runs into separate calls (elbow rebuild / shoulder rebuild / place + check / export); after a timeout, query the state before re-running |

## 4. Design and ergonomics (from the body scan and fitting)

- **Scan accuracy is about ±5 mm.** The printed elbow fits although the scan says it is 5–7 mm tight. Treat small negative gaps to the arm as noise; torso gaps below 10 mm are real.
- **The hanging arm rests on the ribs.** Rings that wrap the medial side press into the ribs and armpit. Wrap only the back and outer side, close with a strap, and rest the exo at 20° abduction.
- **No band across the back of the upper arm mid-length:** it pinches the triceps. With the pipes fixed at both ends (near ring + rigid pipe head, ~100 mm apart) a mid support adds nothing.
- **Armpit fold zone:** no hard parts about 170–205 mm above the elbow on the back-medial side. The pipe head is at 155 mm.
- **Load path:** frame → hip belt carries the load. Backpack straps hold the frame to the back. A rigid shoulder saddle was redundant once there was a frame, straps and a belt.
- **Joints that carry the arm:** no small bolted lugs on thin bands and no single-sided cantilevers. Use one-piece parts, a two-sided fork (double shear) with a through-bolt, Y-joins instead of square corners, and deep blind pipe sockets with screws.
- **Bearings:** a 6806 at ~1.1 kN is far from its limit. Stiffness comes from bearing spacing and the printed structure around it, not bearing size.
- **Kinematics:** both shoulder axes pass through the glenohumeral joint (GH). Parts that turn with the arm keep a constant gap to it; check them against the **torso** across the range. Fixed parts are checked at rest.
- **Yoke routing:** above GH it swings into the neck and saddle under abduction; near the abduction axis it barely moves. A link inside the hinge collides with the deltoid bulge.
- **Balance:** a one-arm exo sits about 96 mm right of the spine. Use a symmetric frame and put the battery at the left mount block.
- **Earlier elbow lessons:**
  - no hard parts on the front of the forearm near the elbow (biceps pinch at full flexion);
  - parts must pass through the bearing bore;
  - delicate lips break;
  - fillet before drilling, and drill pipe holes last.
- Keep the full scan (hands, head, legs). Trim only the Fusion reference copies.

## 5. Verification routine (run after every change)

1. Fusion interference across all bodies, **excluding** coincident faces. Report cross-component hits only.
2. Body clearance against the scan distance fields at rest (`exoarm2-scan/tools/check_fusion.py`).
3. Shoulder range-of-motion sweep: abduction 20–60° × flexion −20–120°, against the torso and the fixed exo parts.
4. The elbow's own 0–135° sweep and door sweeps (`concepts.main`).
5. Print checks: one watertight shell per STL; oriented box within the bed.
6. A screenshot at the joint in question. Numbers can hide ugly geometry.

## 6. Working agreements with the user

- Physical fit tests beat the scan. Ask what fit well or tight after each print.
- Print on a Bambu P1S (256 mm cube). Rounded skin-side edges. Robust over minimal.
- Left/right symmetry through Fusion mirror features, so edits on the right carry over.
- When a request is ambiguous (e.g. "rotate the yoke higher"), state the interpretation explicitly and offer the alternative.
- When something needs the user's hand (MCP reconnect, credentials), say so in one line rather than building workarounds.

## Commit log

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2026-09-15 Replace cinematic walk clips with joint lift motion
    Coordinated hip-to-chest lift, shoulder sheave close-up, elbow antagonist wrap, operator view.
2026-09-15 Add elbow CAD: buy the sheave, print the forks
    McMaster 3434T121, 3/4 in shaft, 25 mm tubes, Jagwire garage cable.
    Human arm numbers and τ = T×r for 5 kg vs 15 kg. Shoulder is next.
    [assembly_preview.stl, cdx-3r-elbow.scad, print_bowden_anchor.stl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]
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2026-09-15 Put the elbow sheave outside the cuffs
    Wearable brace: arm through C-rings, lateral plate carries the McMaster
    sheave, medial plate is a hinge only. No shaft through flesh.
    [assembly_preview.stl, assembly_worn.stl, print_bowden_anchor.stl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]
2026-09-15 Bolt-on McMaster sheave, 608-2RS idlers, 3/4 in shoulder screw
    3434T121 trapped by 91273A274. Two 6455K44 bearings press into printed
    cups on the lateral plate. Same hole takes 3434T157 later.
    [assembly_preview.stl, assembly_worn.stl, print_fork_lateral.stl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]
2026-09-15 Color-code every elbow part
    Cuffs ice/teal, plates titanium/slate, sheave gold, 608 orange,
    shoulder screw carbon, nylock red, stop yellow, ghost arm skin.
    [anchor.stl, arm.stl, assembly_worn.stl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]
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2026-09-15 Show where the elbow cables actually connect
    Housing stops in green ferrules on the upper-arm plate. Inners wrap the
    sheave and pinch on clamps — not on the cuff. Plate is split so the joint can flex.
    [anchor.stl, assembly_preview.stl, assembly_worn.stl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]
2026-09-15 Route Bowden up the upper arm to the shoulder, not out the wrist
    [anchor.stl, arm.stl, assembly_preview.stl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]
2026-09-15 Add shoulder 2R CAD: flexion lateral, abduction posterior
    Same McMaster 3434T121 stack as the elbow. Elbow cables pass a comb
    and do not wrap the shoulder sheaves. Cables go up/back to the pack.
    [abd_yoke.stl, anchor.stl, arm.stl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]
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2026-09-15 Fix STL viewer: wait for layout, open by default, fallback assembly
2026-09-15 Add backpack CAD: D6374 winches, Hailong 48 V, ODrive S1, cable bulkhead
    Three 10:1 planetaries, printed drums, XT90, six M5 barrel adjusters.
    Housing stops at the pack. Inners go to the drums.
    [assembly_preview.stl, assembly_worn.stl, battery.stl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]
2026-09-15 Combine elbow, shoulder, and pack; load on saddle and hip belt
    Amber trapezius saddle and red forearm park rest. Cuffs couple torque.
    They do not hang the exo on the biceps.
    [assembly_preview.stl, assembly_worn.stl, beam.stl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]
2026-09-15 Fix system pose: standing rest, pack on the back, belt around the waist
    Torso was a cylinder on its side and the pack sat on the arm. Arm now hangs,
    forearm on the red park rest, saddle on the trapezius.
    [assembly_preview.stl, assembly_worn.stl, beam.stl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]
2026-09-15 Fix rest pose: forearm across the belly, saddle bolted, cradle not a lock
    Yoke tubes meet a socket on the saddle; UA beam starts there. U-cradle is
    open upward — lift out to move. Bowden + M5 barrels from pack to sheaves.
    [assembly_preview.stl, assembly_worn.stl, beam.stl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]
2026-09-15 Fix STL viewer: one WebGL context, one loader per file
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2026-09-15 Shrink backpack to a 20 L shell on a real torso
    Was a 400×280×120 wardrobe. Now 220×280×80 against the back.
    [assembly_preview.stl, assembly_worn.stl, battery.stl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]
2026-09-15 STL viewer: still first, one mesh on Load 3D, no 24-file swap
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2026-09-15 Replace matplotlib CAD stills with captured 3D orbit shots
    System, right arm, and elbow close-ups from the live viewer.
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2026-09-15 Add modular carbon fairings that screw onto the skeleton
    UA, forearm, deltoid, scapula, pack tub + lid. 2 mm slip, M4 bosses.
    No load in the shells. Stage 05 on the site.
    [ar_deltoid.stl, ar_fa.stl, ar_led.stl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]
2026-09-15 Rebuild armor as overlapping sport dishes, joints left open
    Deltoid dome, floating bicep, forearm plate, formed pack with drum
    windows. Elbow and shoulder sheaves stay in the gaps.
    [ar_deltoid.stl, ar_fa.stl, ar_led.stl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]
2026-09-15 Deltoid is a circular joint window around a dual sheave stack
    Carbon panel with a hole, machined lip, LED ring, 3434T121 pair in
    the opening. Frame vs plating. Sketchfab mesh not imported.
    [ar_bezel.stl, ar_deltoid.stl, ar_fa.stl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]
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2026-09-27 Add Fusion models, build scripts and elbow test prints
    cad/fusion: scripts that rebuild the CDX-3R CAD in Autodesk Fusion.
    - build.py, fxlib.py, elbow.py, mech.py, armor.py: the existing arm (elbow,
    shoulder, backpack, system, armor, wearer) as Fusion solids; every layer
    checked against its reference mesh (114 layers within 0.85 mm).
    - concepts.py: new elbow concept B. PVC-pipe arm units (3 rear pipes, forearm
    tapering to the wrist), two-sided 6806 bearing joint in elbow shells,
    hyperextension ledge and 135 deg flexion hard stop, side-opening wrist
    cuff. Re-runs collision sweeps, stop and soft-tissue checks, and an exact
    pipe-path check (0.0 mm3 in the way).
    - models/: exported .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
    [00_fit_coupon_bearing_pockets.stl, 00_fit_coupon_pipe_holes.stl, 01_upper_arm_elbow_piece.stl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]
2026-09-28 Elbow concept B: bolted axles, M3 hardware, pipe screws, rounded edges
    Fusion model and scripts (cad/fusion):
    - Bearing axle bolted to the forearm hub with a pilot + 3 x M3 into heat-set
    inserts; the inner-ring shoulder moved onto the hub so the plain Ø30 axle
    passes through the bearing bore (the old shoulder made it unassemblable).
    - Housing lip clears the bearing seal; covers screw on with 6 x M3 into
    inserts (the housings had no holes before).
    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
    [00_fit_coupon_bearing_pockets.stl, 00_fit_coupon_pipe_holes.stl, 01_upper_arm_elbow_piece.stl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]
2026-09-30 Shoulder + back system on the body scan; elbow v10; BOM and lessons
    Shoulder + back (cad/fusion/shoulder.py, models/cdx-3r-shoulder-back.f3d):
    - Laid out on the exoarm2 Gaussian-splat body scan (pipeline in cad/scan/).
    - PVC back frame with printed nodes; L/R symmetric through Fusion mirror
    features; strap anchors with flared bases; split bottom node joined by a
    U-channel splice (8 x M3 into inserts).
    - Abduction hinge: 2 x 6806 in the mount block, printed sleeve, M8 x 100.
    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
    [00_fit_coupon_bearing_pockets.stl, 00_fit_coupon_pipe_holes.stl, 01_upper_arm_elbow_piece.stl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]
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2026-09-30 ruthex M3 x 5.7 inserts (7 mm holes), #4 pipe screws; docs and BOM updated
    - Insert holes Ø4.0 x 7 deep for ruthex RX-M3 x 5.7: elbow hubs and housings,
    bottom-node splice. Inserts modelled at their real length; no interference.
    - Pipe screws are #4 x 3/8 pan-head self-tapping (the Ø3.2 holes and Ø6.5
    counterbores already fit); stale #6 / self-drilling references removed.
    - Notes for already-printed v9 elbow parts (press inserts flush, M3 x 10 in the
    v9 axles).
    - Re-exported elbow v10 and shoulder-back v2 print sets and both .f3d models.
    [01_upper_arm_elbow_piece.stl, 02_forearm_elbow_piece.stl, 03_bearing_axle_print2.stl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]
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2026-09-30 Wrist-cuff latch for a 5 mm ball-lock pin; BOM pin and bearing links
    - Cuff latch knuckles (+X) Ø5.2 for a Ø5 x 30 mm ball-lock pin (METERXITY,
    Prime); hinge side stays Ø4.2 for the Ø4 x 25 dowel. Elbow and door sweeps clear.
    - Re-exported elbow v10 (05 wrist ring, 06 cuff) and the elbow .f3d.
    - BOM: quick-release pin, 6806 and 6808 bearing links.
    [05_wrist_ring.stl, 06_wrist_cuff.stl, cdx-3r-elbow-concepts.f3d]
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2026-09-30 New README around the Fusion design; motion render; BOM and harness updates
    - README rewritten around the current design: the motion animation at the top (the
    scanned arm moves with the exo, the camera orbits from back to right side), renders of
    the exo on the scanned body, how each part works, build links. The old concept
    README is kept at docs/concept-README.md.
    - docs/images: Fusion renders, cdx3r-motion.gif and cdx3r-motion.mp4.
    - BOM: product thumbnails; Prime links for the parts being ordered; magnets for
    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
    [Bottom_node_L.stl, Bottom_node_R.stl, cdx-3r-shoulder-back.f3d]
2026-10-05 Assembly guide with step animations; shoulder-girdle DOF extension note; yoke beam check
    - docs/ASSEMBLY.md: plain-language, step-by-step build guide (parts checklists, tools,
    skills, PVC cuts at point of use, checks), with captioned exploded-assembly GIFs
    rendered from the Fusion model (docs/images/assembly/).
    - docs/extensions/shoulder-girdle-dof.md: parked 4th DOF (shoulder blade motion) and
    the abduction-hinge load-path fixes.
    - cad/scan/tools/yoke_fea.py: beam FE sag/stress check of the yoke.
    - README: links to the guide and the extension note.
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2026-10-07 Abduction washer: 32 mm OD (a 30 mm washer slips into the 6806 bore)
    The rear washer must clamp the 6806 inner ring: OD > 30 (bore) and <= 33 (ring
    land). BOM row and Amazon link (M8 x 32 x 1.2, 304), assembly guide step 3
    (flush-sleeve check, wrong-washer warning), print README, model parameter and
    LESSONS updated.
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2026-10-18 Shoulder girdle v3b + chained shoulder rest: model, print set v3, assembly guide
    - Shoulder tower slides over the top node (flush tenon); lift parallelogram with
    a 22 N gas strut on eyelet forks (M6 thumb screws into hidden nuts); SCARA
    tray/lid links with GT2 200 mm belts on printed 35-tooth pulleys
    - Chained shoulder rest: bracket on a pivot boss with an M6 thumb-screw arc-slot
    lock, root arm + 3 honeycomb blades on M6 x 70 clevis pins, foam pads
    - prints/shoulder-back-v3: 30 STLs with orientation and v2 comparison
    - docs/ASSEMBLY.md rewritten picture-first (details folded), new step GIFs with
    fastener-correct insertion, staging and see-through hidden nuts
    - BOM: shopping list of t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
2026-10-18 Print-ready v3 set: pre-oriented, validated STLs; carriage redesigned for printing
    - All 30 STLs in prints/shoulder-back-v3 are pre-rotated into their print
    orientation (cad/fusion/orient_stls.py) and pass print_validate.py
    (one shell, no thin films); import as is, no slicer auto-orient
    - Lift carriage: flat root disc (the 0.6 mm boss became a printed Ø11x1
    spacer, thin spacers now x6), 45° web under the front cheek, pointed
    roofs on every horizontal hole, nut drop slot clear of the bolt tunnels,
    flat cut by the upper pivot nut (no crescent, no 0.05 mm film)
    - Strut ends are eyelets: M6 x 16 socket-head screws through printed forks
    into hidden M6 nuts (BOM: MewuDecor M6 x 16);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
2026-10-18 Shoulder rest pivot bolt, model checks on every commit, first stress tests
    - Rest bracket held by an M6 x 65 through the tower (was one M6 into a nut behind
    1.7 mm); root hinge 10 mm out so the bolt head clears it; printed washers (31).
    - Model split into module documents + linked assembly (split.py).
    - Model checks (checks.py): fastener grip, static collisions and a motion sweep
    through 22 poses, run on every export; reports stamped with the model-code hash;
    the pre-commit hook refuses model/print commits without current, passing reports.
    Two open motion findings listed as known (docs/bugs).
    - docs/bugs: one note per bug, what it cost, and what now catches it.
    - docs/stress: Fusion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
2026-10-18 Rest pivot: crush spacer between the tower plates; retrofit for towers printed before 18 Oct
    - 32_rest_pivot_spacer: printed tube between the tower's two plates on the M6 x 65,
    so tightening the back nuts can't squeeze the plates together (the bolt is only
    threaded near its tip). Checks pass; the lift link clears it in all 22 poses.
    - Retrofit for older towers (their back plate has no material around the bolt line):
    M6 x 30 through the front plate into a captive nut in a printed 30 mm backer
    (retrofit/rest_backer_retrofit.stl, cad/fusion/retrofit_backer.py).
    - Assembly guide, BOM (M6 x 30, ordered), print list and bug note updated.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
2026-10-20 Fix the PVC cut list table in the assembly guide
    The separator row had 3 columns for a 4-column header, so the table
    showed as raw text instead of rendering.
2026-10-20 Assembly guide: buy an M8 x 75 instead of cutting a bolt; fix broken tables; pausable player
    - SCARA elbow bolt: buy an M8 x 75 socket head (fully threaded) instead of cutting
    an M8 x 100; guide, tools list, skills and BOM updated, SCARA animation caption too.
    - Back-frame animation caption said the right backbone is 583 mm; it is 568 mm.
    - Six BOM tables and the shopping list had rows or separators with the wrong
    number of columns, so they showed as raw text. Fixed; tools/md_tables.py checks
    every table row and the pre-commit hook runs it on staged markdown.
    - tools/assembly_player.py: turns the step GIFs into a page with play / pause /
    frame stepping (GIFs can't be paused).
    Co-Aut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
2026-10-21 Gripper prototype 3 (fold-up): model, checks, prints, assembly guide
    - gripper3.py: fold-up gripper with Y-link trigger drive, TPU fin-ray C-cup
    claws, extension return spring, sliding pipe clamps and Velcro stow pad
    - gripper.py (prototype 2, sliding) kept for reference; both .f3d archived
    - Design rules per module (one body, claw roots, tips, sharp edges, spring,
    grip force, trigger neck) and gripper collision/motion/fastener reports
    - print_validate stricter: 1.2 mm walls, 0.8 mm floors, thin strips
    - prints/gripper3-v1: 7 oriented STLs (3 claws in TPU)
    - ASSEMBLY step 11 with colour pictures, BOM buy list, README, LESSONS
    - Shoulder reports re-run with gripper 3 in the assembly
    Co-A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
2026-10-21 Gripper 3 carrier: broad neck under the hinge knuckle
    The knuckle round the M8 hinge bolt joined the bridge through a ~3 mm sliver
    and would have snapped. The bridge outline now leaves the knuckle at its front
    and runs tangent to its back: 25.8 mm of solid where it was 5.8 (measured
    2 mm outside the knuckle).
    - knuckle_neck_rules: measures the neck on the real outline (fails the old
    shape, >= 0.8 x knuckle diameter)
    - the knuckle strength load uses that measured width, not a fixed 26 mm
    - carrier re-exported; all gripper and assembly checks re-run
2026-10-21 Gripper 3 base: round every edge, ramp up to the stow pad
    - the no-sharp-edges rule now covers the whole base (hole and pipe-bore
    edges excepted, they set fits); it failed with 69 sharp edges
    - every other base edge rounded 1.5 mm
    - the rib's sloped end runs straight up into the stow pad: no 7 mm step
    - base re-exported; all gripper and assembly checks re-run
2026-10-21 Gripper 3 collar: goes on over the nose; slide-on test for every part
    The collar's bore (r 26.4) was smaller than the carrier's nose (r 27.5) and
    the bridge closes the hub's other end: it could not go on. The carrier is
    already printed, so the collar changes: bore r 27.8, and three pads inside
    it (at the claw angles) centre it on the hub with 0.3 mm play and pass
    through the nose's claw slots on the way on.
    - insertion_rules + INSERTION: each part, in the guide's order, slides in
    along its path 1 mm at a time and must not cut into parts already on.
    Fails the old collar (blocked 17 mm out); showed the claws need the
    collar parked 7 mm back, which sets the new order.
    - ASSEMBLY 11.3/11.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
2026-10-25 End plate: captive E nut; screw checks for unheld parts and sim joints
    The SCARA end plate hung below the nut meant to hold it: the E nyloc sat in
    a pocket open toward the bolt head, so tightening pulled the nut out of it
    and the clamp stack ended above the plate. The nut is now captive inside
    the plate under a 4 mm ceiling: a side slot from the front with a V end
    that centres it on the bolt, and a 5 mm push-out hole from the back. One
    more 1 mm spacer between the plate and link 2 (thin spacers x7).
    How it was missed, and what catches it now (fastener_check.py):
    - THREAD: every machine screw ends in a modelled nut or insert
    - HELD: every printed part a fastener passes lies between its head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
2026-10-26 Elbow: Dynamixel XL430-W250-T case on the outer side; stress to-do
    The elbow swung too freely: the outer bearing cover is replaced by a case
    for an XL430-W250-T (sizes from Robotis' STEP in koch-v1-1). The case bolts
    to the cover's 6 inserts; the servo lies along the upper arm, horn on the
    elbow axis. A horn coupler (2 x M2.5 into the horn) drops 3 pegs into the
    outer axle's screw pockets, so the forearm turns the horn. New outer axle:
    same screws and inserts, deeper pockets, Ø36 flange outside the bearing.
    Both printed elbow pieces are unchanged.
    - prints/elbow-servo-v1: case, strap, horn coupler, servo axle; checks,
    README with assembly steps and a warning not to backdrive the servo
    -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
2026-10-27 Servo coupler: centre hole for the horn's screw; horn fit check
    The XL430 STEP has no horn centre screw, so the coupler sat on its head.
    Model the head, cut a 7 mm hole through the coupler, and check the coupler
    against the horn on every elbow build (failed on the old coupler: 39 mm3).
2026-10-28 Gripper: stronger collar cheeks, grip as post + sleeve, clamp screws; key access check
    - Collar: the tail-pin cheeks snapped (2 mm round the slot). 6 mm wide, out
    to r 40 on sloped pads, M3 x 25 tail pins. tail_cheek_rules().
    - Grip: its 4 screw heads were sealed inside. Now a top plate with a cross
    post (heads reachable from below) and a sleeve that slides over it,
    one M3 x 8 up into the post's foot.
    - Pipe clamps: M3 x 10 thumb screws reached 0.75 mm past the pipe; M3 x 12.
    clamp_rules().
    - fastener_check ACCESS: a key must reach every screw head (15 mm clear),
    except parts fitted after it. Failed on the old grip; flagged the rest
    pivot bolt under the root arm (open bug).
    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
